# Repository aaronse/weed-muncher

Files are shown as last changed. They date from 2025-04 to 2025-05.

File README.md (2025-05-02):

# Project: Pet Sapling Savior, or, Pet Weed Euthanizer?

## Description
An Arduino or ESP32 powered, Mostly 3D‐Printed Smart Pet Weed Euthanizer/Relocator that grips unwanted plants, gently uproots them.  Use to annihilate, or deposit sapling-worthy seedlings into your chosen grow tray—combining garden cleanup, and with mini reforestation.

Inspired by conversations on V1 Engineering forum, see https://forum.v1e.com/t/how-about-a-m3dpmower/36759  topic for context/details.

Built two separate versions, a V1 Engineering Jackpot with FluidNC on ESP32, and, an Arduino Nano 33 IoT version.

.STL files available on [Printables](https://www.printables.com/model/1276001-pet-weed-euthanizer-or-pet-sapling-savior-in-progr)

This Project was inspired by conversations on V1 Engineering forum, see https://forum.v1e.com/t/how-about-a-m3dpmower/36759  topic for context/details.   

ASMR video of earlier Iteration #2 tests…



<table><tr>
<td>

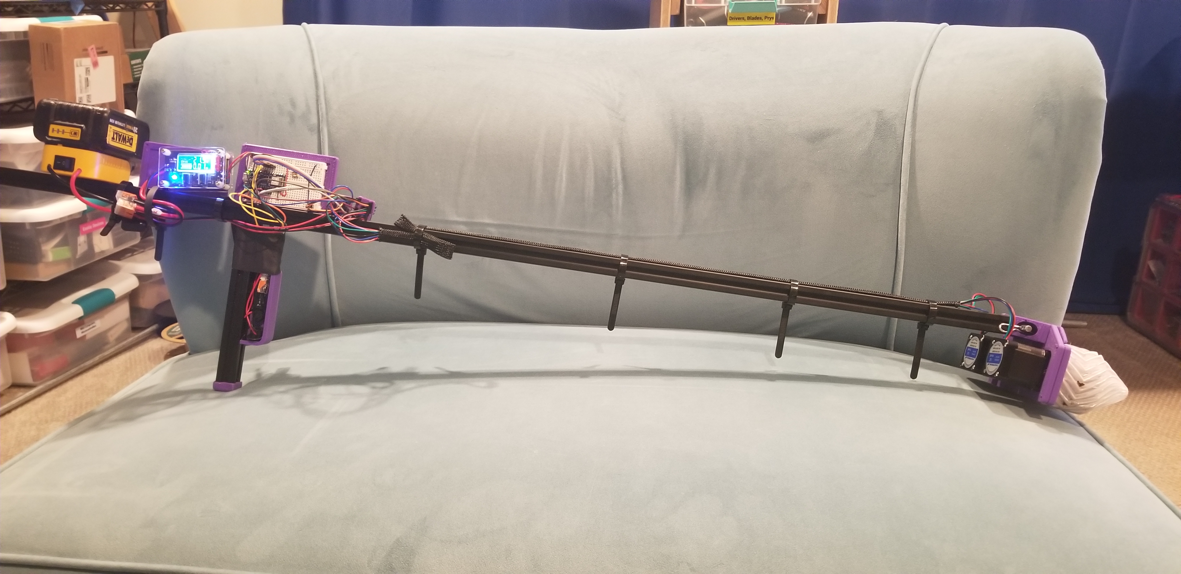
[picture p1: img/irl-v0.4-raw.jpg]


</td>
<td>

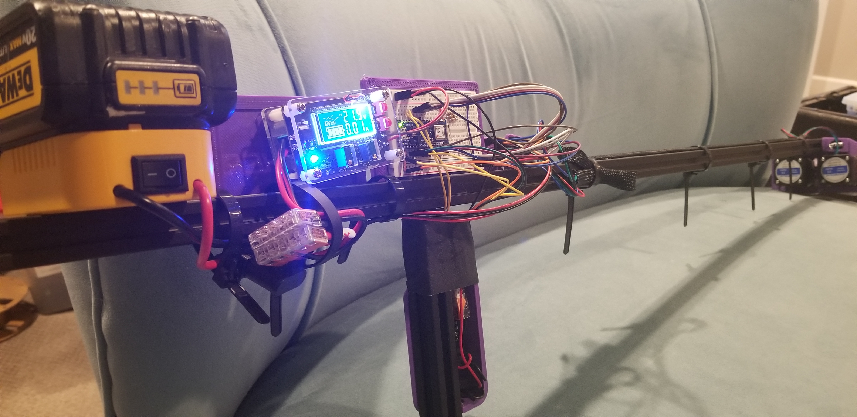
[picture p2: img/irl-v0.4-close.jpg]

</td>
<td>

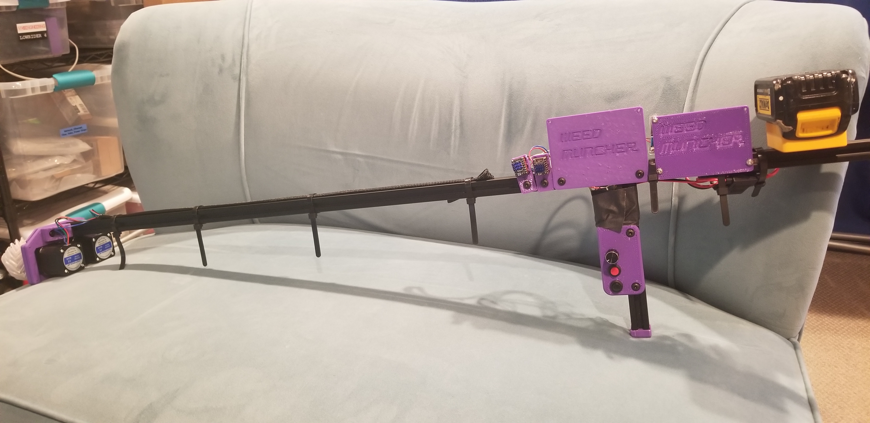
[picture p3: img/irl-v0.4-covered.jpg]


</td>
</tr></table>

### WHY?
- I hate weeding, and avoid chemicals, plus I'd like to relocate otherwise unwanted saplings to areas needing reforesting, or, yards of people that like/deserve weeds 😉.
- Best selling Weeders are unable to grip smaller weeds/saplings like the ton of Maple tree ones that drove me to this. 
- This is Phase 1 of having IOT+AI powered machines to do my bidding, before they make me do theirs.
 
### WHAT's SPECIAL?
- Fast cordless yard fun way to relocate pet saplings, or, euthanize pet weeds.  
- Design includes many components that can be repurposed for other DIY tools.
- Uses mix of TPU infill/density and [Linear Spring Compliant Mechanisms](https://forum.v1e.com/t/linear-spring-compliant-mechanisms-designing-calculating-force-and-deflection/48891) to simulate pressure exerted by human hands gripping and pulling saplings/weeds without breaking them (well tries too...). 
- Today's chemical free [Best selling Weeders](https://www.amazon.com/gp/bestsellers/lawn-garden/553934) are designed for either large deep rooted weeds, or, for people to bend and kneed down to grip and pull out small weeds by hand.  There's got to be a better way...  Maybe this DIY tool ?
- Pulling small saplings/weeds saves time compared to repeatedly cutting/trimming weeds until their root system exhausts and dies.
- **NO Coding** needed for FluidNC controller board based builds.  Just upload [config.yaml](fluidnc/config.yaml) via Web UI, restart, then go relocating/hunting...

## Functions
- Grip, pull and discard, or, collect for relocation.
- Normal grip and pull.
- Turbo grip and pull, mode for rapid munching, and suborbital sapling/weed launching. 

## 2. Software & Hardware

- [x] **Software List**: CAD/design tools and libraries...
  - [VS Code](https://code.visualstudio.com/), [Arduino IDE](https://www.arduino.cc/en/software/), [PlatformIO](https://platformio.org/), [FluidNC](http://wiki.fluidnc.com/en/home)/[ESP3D](https://github.com/luc-github/ESP3D), [Fusion 360](https://www.autodesk.com/products/fusion-360), [OpenSCAD](https://openscad.org/), [Fritzing](https://fritzing.org/).

- [x] **Hardware List**: 
    - BOM contains latest set of parts that are working for me.  I tried many more components than what are listed here.  Let me know if you want to see the full list, only shared subset here to keep instructions straight forward.   
      - Recommend 2x Nema 17 84oz with 2x TMC2209 for max pulling fun :-)
      - **Power**:
        - [AI chat about Buck convertor options](https://chatgpt.com/share/680bc146-582c-800b-8d66-930ea82643ff)
  - [X] Provided info to build either (A) Arduino, or (B) V1 Engineering Fluid NC ESP32 based build :
    - [X] Option (A), Arduino Controller:
      - https://store.arduino.cc/products/arduino-nano-33-iot-with-headers
    - [X] Option (B), V1 Engineering JackPot Controller (ESP32, FluidNC): 
      - https://www.v1e.com/products/jackpot-cnc-controller
    
## BOM

| Total Price | Description | Link / Comments |
|---:|:---|:---|
| 27 | Arduino Nano 33 IoT with Headers [ABX00032] | "https://www.amazon.com/dp/B07WPFQZQ1<br/>- https://store.arduino.cc/products/arduino-nano-33-iot-with-headers<br/>- https://mm.digikey.com/Volume0/opasdata/d220001/medias/docus/697/ABX00032_Web.pdf<br/>- https://docs.arduino.cc/hardware/nano-33-iot/#tech-specs<br/>- https://mm.digikey.com/Volume0/opasdata/d220001/medias/docus/697/ABX00032_Web.pdf<br/>- https://docs.arduino.cc/hardware/nano-33-iot/#tech-specs" |
| 28 | STEPPERONLINE 2A 59Ncm 84oz Nema 17 Stepper Motor Bipolar 48mm | https://www.amazon.com/dp/B00PNEQKC0 |
| 10 | 12pcs 12mm Mini Latching Push Button Switch ON-Off AC 250V/1.5A 125V/3A | https://www.amazon.com/dp/B0CGTXMLKL |
| 6 | 15pcs 220uF 35V 8x12mm Electrolytic Capacitor 220 UF MFD 35 Volt 0.32x0.47in Aluminum Capacitors | https://www.amazon.com/dp/B0CMQCG3M8 |
| 11 | 2pcs 12V-36V DC Voltage Protection Module Digital Low Voltage Protector Disconnect Switch Over Discharge Protection Module | https://www.amazon.com/dp/B07QNXM4LS |
| 16 | 2pcs Switched, Fused Power Adapter for Dewalt 20V Battery | https://www.amazon.com/dp/B0CRK9CN4D |
| 21 | 28pcs WAGO 221 Lever Nuts, Assortment with Case, Includes 221-2401, 221-412, 221-413, 221-415 | https://www.amazon.com/dp/B0CJ5QF3VX |
| 9 | 6pcs ELEGOO Half Breadboard Kit (400 Points, 2 pairs of power rails) | https://www.amazon.com/dp/B0CYPVMK9J |
| 10 | 630pcs BOJACK 0-to-1M Ohm 1% 1/4W (17 diff values) Metal Film Resistor Kit | https://www.amazon.com/dp/B07QXP4KVZ |
| 15 | DROK LCD Screen DC Buck Converter Adjustable Voltage Regulator 12V 6V-32V to 1.5-32V 5A, LCD Screen Step Down Converter with USB Port and Protective Case | https://www.amazon.com/dp/B07JZ2GQJF |

### 3. Wiring Diagram
- [X] Draw clear schematic (PNG/PDF).
- [X] Annotate each connection with a brief caption.

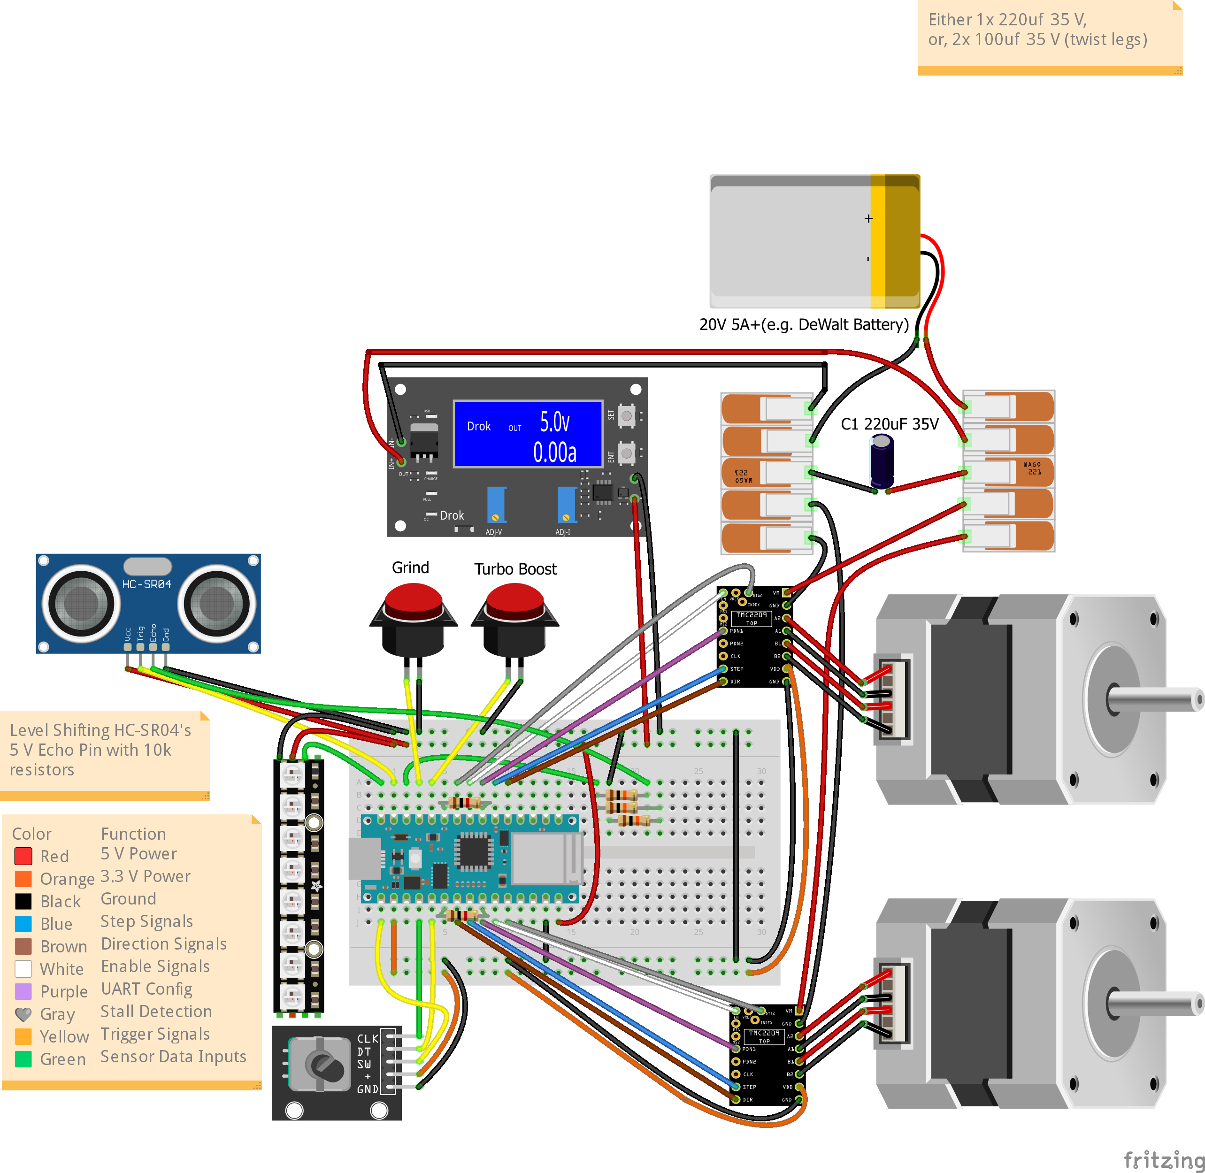
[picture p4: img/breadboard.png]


### Arduino Nano 33 IoT (3.3 V logic)

| Function | Board Pin | Device Pin | Wire Color |
|---|---|---|---|
| STEP1 | D3 | STEP | 🟦 Blue |
| DIR1 | D2 | DIR | 🟫 Brown |
| EN1 | D5 | EN | ⬜ White |
| TX1 (to PDN_UART1) | D7 | TX (with 1kΩ) | 🟪 Purple  |
| RX1 (from PDN_UART1) | D4 | RX | 🟪 Purple  |
| StallGuard1 (DIAG1) | D6 | DIAG | 🩶 Gray |
| STEP2 | D18 | STEP | 🟦 Blue |
| DIR2 | D17 | DIR | 🟫 Brown |
| EN2 | D20 | EN | ⬜ White |
| TX2 (to PDN_UART2) | D16 | TX (with 1kΩ) | 🟪 Purple  |
| RX2 (from PDN_UART2) | D19 | RX | 🟪 Purple  |
| StallGuard2 (DIAG2) | D21 | DIAG | 🩶 Gray |
| Rotary Encoder CLK | D14 | CLK | 🟩 Green |
| Rotary Encoder DT | D15 | DT | 🟨 Yellow  |
| Rotary Encoder SW | D13 | SW | 🟨 Yellow  |
| Turbo Button | D8 | Button | 🟨 Yellow  |
| Grind Button | D9 | Button | 🟨 Yellow  |
| US Trigger (TRIG) | D11 | Trigger | 🟨 Yellow  |
| US Echo (ECHO) | D10 | Echo | 🟩 Green |
| NeoPixel Data | D12 | NeoPixel | ⬜ White |

### 4. Code
- [x] Fully commented Arduino sketch.
- [x] Summary of code behavior.
  - The Weed Puller wakes up by setting up its buttons, rotary encoder, and motor drivers for smooth control and stall detection. It reads the Grind and Turbo buttons, the rotary encoder for speed adjustment, and the encoder switch to set the pulling direction.

  - Pressing Grind lets you pull weeds at a custom speed; Turbo gives you max power instantly. If the motors detect a stall, the system shuts them down and flashes a red warning until you're ready to go again. It also keeps an eye on weed distance with an ultrasonic sensor and shows real-time status over USB for easy debugging.

- [x] Full code repository at [https://github.com/aaronse/weed-muncher](https://github.com/aaronse/weed-muncher)

### 5. 3D Printing Instructions

| Qty | File Name | Material | Layer Height | Infill | Support | Print Settings | Purpose/Comment |
|:---|:---|:---|:---|:---|:---|:---|:---|
| 1 | chasis.stl | PETG | 0.32mm | 40% | No | 0.6mm noz, 3 walls, 3 top/bot layers | Mount grinder assembly to pole mounts |
| 1 | grinder-tire-tapered.stl | HS TPU | 0.32mm | 0% | No | 0.6mm noz, 1 wall, 1 top/bot layer | Tapered double helical grip 'n pull |
| 1 | grinder-tire-tapered-mir.stl | HS TPU | 0.32mm | 0% | No | 0.6mm noz, 1 wall, 1 top/bot layer | Mirrored evil twin for meshing. |
| 2 | grinder-core.stl | PETG | 0.32mm | 40% | No | 0.6mm noz, 3 walls, 3 top/bot layers | Based on metal 2020 right angle brackets, but customized for this build |
| 1 | grinder-flex-mount.stl | PETG | 0.32mm | 40% | No | 0.6mm noz, 3 walls, 3 top/bot layers | Plate to mount Steppers motors with integrated Linear spring compliant mechanism. |
| 1 | guard-grip-gt2.stl | PETG | 0.32mm | 40% | No | 0.6mm noz, 3 walls, 3 top/bot layers | Holds brackets, and grips dust/debris guard to protect steppers. |
| 2 | 2020-bracket-right-angle.stl | | 0.32mm | 40% | No | 0.6mm noz, 3 walls, 3 top/bot layers | Mount pole to grinder assembly. |
| 2 | 2020-cap.stl | HS TPU | 0.32mm | 20% | No | 0.6mm noz, 3 walls, 3 top/bot layers | End CAPs to make 2020 less stabby. |
| 0 or 1 | 2020-mount-breadboard-half.stl | PETG | 0.32mm | 20% | No | 0.6mm noz, 3 walls, 3 top/bot layers | ONLY Arduino build.  Mount for half breadboards, includes logo upside down, trick print.  Consider the separate _base_ and _frame_ versions if your printer bed isn't sticky. |
| 0 or 1 | 2020-mount-breadboard-half-base.stl  | PETG | 0.32mm | 20% | No | 0.6mm noz, 3 walls, 3 top/bot layers | ONLY Arduino build, maybe…  This "base" and "frame" are for the meek not comfortable printing engraved logo upside down. |
| 0 or 1 | 2020-mount-breadboard-half-frame.stl | PETG | 0.32mm | 20% | No | 0.6mm noz, 3 walls, 3 top/bot layers | ONLY Arduino build, maybe…  See above |
| 0 or 2 | 2020-mount-tmc2209.stl | TPU | 0.32mm | 20% | No | 0.6mm noz, 3 walls, 3 top/bot layers | ONLY Arduino build.  Temporary mounts for TMC2209 until I figure out better solution.  They don't fit in breadboards. |
| 0 or 1 | 2020-mount-jackpot.stl | PETG | 0.32mm | 20% | No | 0.6mm noz, 3 walls, 3 top/bot layers | ONLY for V1 Engineering Jackpot build |
| 0 or 1 | trigger-lefty.stl | PETG | 0.32mm | 40% | No | 0.6mm noz, 3 walls, 3 top/bot layers | ONLY if User is Left handed |
| 0 or 1 | trigger-righty.stl | PETG | 0.32mm | 40% | No | 0.6mm noz, 3 walls, 3 top/bot layers | ONLY if User is Right handed |

### 6. Assembly Instructions
- [ ] Step-by-step bullets (e.g. “1. Insert stepper into jaw housing; 2. Route wires through handle; …”).
- [ ] Alignment or torque tips (e.g. jaw mesh clearance).

### 7. Demo & Usage Instructions
- [ ] Power-on and mode selection (Pull vs. Release).
- [ ] Operating tips (e.g. hold at 30° angle, watch for stall-flash).
- [ ] Safety note (keep fingers clear of gears).

### 8. Additional Notes & Tips
- [ ] Troubleshooting pointers (e.g. check wiring if it stalls).
- [ ] Optional enhancements (e.g. add LCD status display).

### 9. Photos & Videos
- [ ] Finished product: multiple angles.
- [ ] Wiring close-ups.
- [ ] In-action demo GIF or short video (pull + relocate cycle).

- Trigger Design
  - https://www.youtube.com/watch?v=H3J8FiLNEtc
  1:07
  - Airwolf trigger, turbo, rockets...
    - 0.35 https://www.youtube.com/watch?v=PigDNRQyNwE
https://installer.fluidnc.com/

## Firmware
- FluidNC
  - http://wiki.fluidnc.com/en/config/control
  - Macros http://wiki.fluidnc.com/en/config/macros
  - Configuring Pins http://wiki.fluidnc.com/en/config/config_IO
  - ESP32 Dev Kit Pins http://wiki.fluidnc.com/en/hardware/esp32_pin_reference
  - IPC via WebSockets/TCP http://wiki.fluidnc.com/en/support/interface/websockets
  - 

## TODO/TASKS
- CAD Design edits
  - Prevent weeds sneaking behind, add funnel/guide?

  - Grinder Assembly
    - Grinder Core
      - Add lip to stop tire pulling towards Flex Mount plate
    - Grinder Tire
      - Reduce rotation angle so 0.4mm layer height slicer doesn't add "top" line segments. 
      - Prevent slip off: More bumps/recesses, or make existing bigger?
      - Modify design so Slicer 0.72mm wall width results in _inner hub wall_ and _tooth wall_ touching/bonding.

## HISTORY
- 1st Tire Print 
  - (3hr 12mins, 15% retractions) Slicer config: 2 walls, alternative wall, infill 20%, 0.32mm layer height
  - Stiffer than expected
- 2nd Grinder Tire print ()
  - (1hr 51mins, 11%) Slice config: 2 walls, 0.66mm, line width, NO alternative wall, 0% infill, 0.36mm layer height
    - ⚠️🤷‍♂️ Counter intuitively, SAVED print time using 0.32mm layer height instead of 0.4mm.  Reason is steep overhang angle of the gear teeth results in more wall material being added, when laying thick layers like 0.4mm.  Added task to reduce rotation angle of sweep, so thicker faster single walls are possible, 
  - Goals flexible print that still grips Grinder Core

## DESIGN
- Grinder Flex Mount
  - Design uses _stepped recess bore holes_, looked at [various bottom recess options](./docs/cads-flat-bottom-recess.htm)
   - To support grabbing weeds of varying thickness, the design uses linear spring compliant mechanism for resistive flex.  Goal is 30N or more resistive force, 3.5mm limited range of motion.
     - Considered [pros/cons of various materials for compliant mechanisms](./docs/compliant-mechanism-materials.htm)
     - Considered [various Open Source FEM software](./docs/fem-software-options.htm)
  - Intentionally spaced mount holes 1" OC for optional pegboard mounting.

- Grinder Wheel Treads
  - Design has conical features with tiller
    - Fusion 360 Coils swept along spiral tapered path 
    - https://www.youtube.com/watch?v=8WW2_HtuV9A
  - Morley Kert, Fusion 360 "Create Form" to make twisted scaled structures Twist
    - https://www.youtube.com/watch?v=FTLb_tus4F4

- Pole to Grinder mounts
  - History/context:
    - Was concerned about 3D print being strong enough.  Designing and printing anyway to confirm/correct my understanding/theory with data...
    - Considered 3D printed like... 
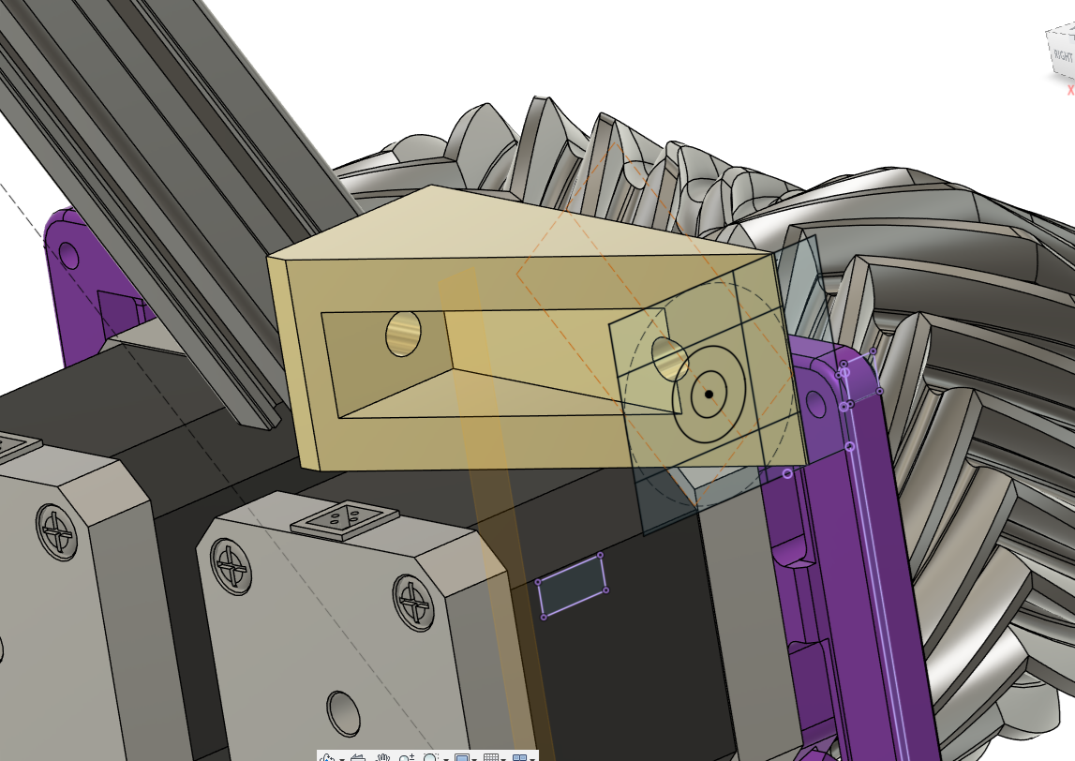
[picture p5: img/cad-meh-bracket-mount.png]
      
    - Considered common easy to source brackets.  Ideally 1" wide with centered holes.
      - Best Selling Corner Braces https://www.homedepot.com/b/Building-Materials-Building-Hardware-Corner-Braces/N-5yc1vZc8hr 
      - https://www.homedepot.com/p/Everbilt-1-in-Steel-Zinc-Plated-Corner-Brace-4-Pack-24590/327599496

## ALTERNATIVE HARDWARE CONSIDERED

- PegBoard (alternative to CNC/Printed plates).
  - Popular 1" OC, 1/4" holes, Pegboard at HomeDepot:
    - Best Seller... Hardboard, painted White Acrylic  [48 in. H x 24 in. W White Pegboard](https://www.homedepot.com/p/Handprint-48-in-H-x-24-in-W-White-Pegboard-109099/202093803)
    - [16 in. H x 16 in. W Plastic Pegboard in Black (50 lbs.)](https://www.homedepot.com/p/Everbilt-16-in-H-x-16-in-W-Plastic-Pegboard-in-Black-50-lbs-814450/317815422)
    - Some popular/accessible options...
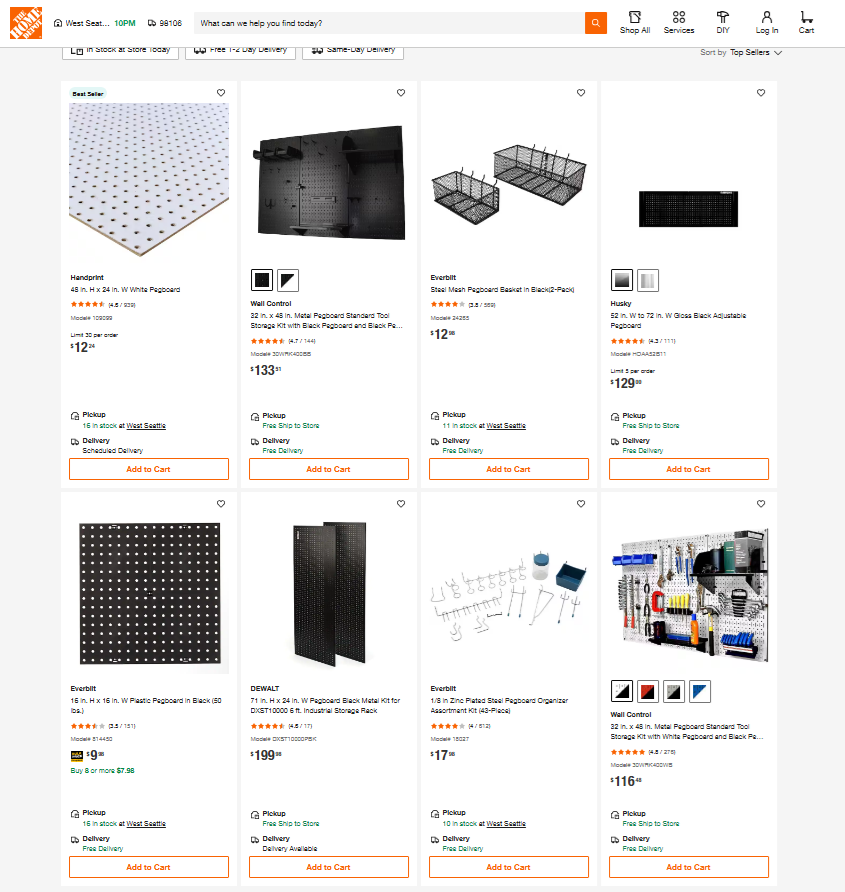
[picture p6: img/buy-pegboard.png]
image|845x892,50%
      

## 📄 License

⚠️ This project is for **personal, non-commercial use only**, and is licensed under the [Creative Commons BY-NC-SA 4.0](https://creativecommons.org/licenses/by-nc-sa/4.0/) license.

You are free to:
- ✅ Use it
- ✅ Remix it
- ✅ Build your own version at home

As long as you:
- ❌ Don't sell it or make money from it
- ✅ Give credit
- ✅ Share under the same license

😏 *Interested in selling parts or kits?*  
Am open to commercial licensing.  Any help paying for my kids' college fees is appreciated, cheers!  Contact via https://github.com/aaronse/weed-muncher/issues

**Commercial use or resale of any parts, models, or derivatives is strictly prohibited.**

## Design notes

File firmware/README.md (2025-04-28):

# Firmware code for Arduino

Built within VS Code using [PlatformIO](https://platformio.org/) extension.

## Target Devices

### Arduino Nano 33 IOT with Headers
- Buy/Info/Specs
  - https://store.arduino.cc/products/arduino-nano-33-iot-with-headers
  - https://mm.digikey.com/Volume0/opasdata/d220001/medias/docus/697/ABX00032_Web.pdf
  - https://docs.arduino.cc/hardware/nano-33-iot/#tech-specs"
- Features
  - IMU LSM6DS3, 6DOF, 3-axis acceleraometer, 3-axis gyroscope
    - Specs and example code https://chatgpt.com/share/680c0183-c3ec-800b-9c23-7b8a9bf442b4
  - BT/Wifi Nina W102 uBlox module 
    - https://chatgpt.com/share/680c0204-ad44-800b-958a-99003f26550e

### FUTURES: ESP32 + Cam
- Example code https://chatgpt.com/share/680c02d7-a82c-800b-a7e2-b9fce2a6de79

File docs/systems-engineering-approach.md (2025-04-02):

You're thinking like a systems architect *and* a product engineer here — and that’s exactly what this kind of project needs. Designing a powerful "AI-assisted inner loop" for hardware development means balancing **creative design**, **accurate geometry**, and **reliable iteration**, and optimizing **how we collaborate** across those stages.

Let’s define a few ways we can seriously **boost our productivity**, reduce friction, and set up a **tight feedback loop**.

---

## 🧠 **1. Clarify Roles in the Inner Loop**

| Role | Human (You) | AI (Me) |
|---|---|---|
| Creative judgment, ergonomics, purpose-driven constraints | ✅ | ❌ |
| Scripting, CAD generation, geometric patterning | ⚠️ Manual / slow | ✅ |
| Iteration, simplification, trade-off suggestions | ✅ | ✅ |
| State introspection, serialization, regeneration | ⚠️ Manual | ✅ (via custom script) |

> **Takeaway:** You steer high-level design intent + edits. I automate structure, generate suggestions, and keep designs clean and repeatable.

---

## ⚙️ **2. Build Reusable Parametric Vocabulary**

Rather than one-off scripts, we define a shared, evolving **“language of components”**, like:

- `MountBracket(innerDiameter, wallThickness, holePattern)`
- `ClawArm(length, width, pivotOffset)`
- `TimingBeltPulleySet(spacing, tensionSlot, mountType)`
- `TPUFingerPad(shape, gripProfile, attachmentMethod)`

We work in **reusable function-based patterns** for mechanical parts. Then:
- I can quickly generate new variants
- You can adjust behavior by tweaking params
- You can eventually combine these into a **modular Fusion component library**

---

## 🔁 **3. Track and Reflect on Manual Changes (Model Inspection Script)**

We'll eventually build a Fusion script that:
- Walks the assembly tree
- Extracts key geometry + transforms
- Serializes into a structured JSON or human-readable format

That lets you:
- Make tweaks directly in Fusion UI
- Export the **state delta**
- Send it back here for clean regeneration or AI-assist tuning

> This closes the loop so we can go **back and forth** between your hands-on edits and my generative help.

---

## 🧩 **4. Capture "Design Context" With Lightweight Metadata**

We should annotate components in a machine-readable way so I understand more about what each piece *does*:
- `TPUFingerPad` has a `gripZone`, `mountFace`, `replaceable = true`
- `GripperArm` has `pullForceVector`, `beltTab`, `pivotAxis`

You could embed these in model naming, script comments, or exported metadata so I can reason about function, not just form.

---

## 🔧 **5. Tooling Infrastructure for Efficient Iteration**

| Tool | Purpose | Notes |
|---|---|---|
| Fusion 360 Add-In (Python) | Generate & edit assemblies | Main modeling tool |
| OpenSCAD / Preview STL | Quick sketches / testing form factor | For off-model prototyping |
| JSON Model Descriptor | Reflective state snapshot | Output from inspection script |
| VS Code + Git | Version scripts + notes | Helps track changes, see diffs |
| Screenshot or video markup | Explain tweaks visually | Feed into AI for updates or fixes |

---

## 🔊 **6. Communication Loop Optimizations**

- You can tell me: *"Rotate gripper arms 5° inward and increase finger length to 75mm, but keep belt spacing the same."*
- I’ll parse that and rewrite your Fusion script or suggest edits to apply in the UI.
- Then you run the state-export script and we compare original vs tweaked designs.

If needed, I can even auto-generate UI overlays or future in-browser design editors based on your design language.

---

## 🚀 Summary: Optimized AI-Human Design Loop

1. **Start** with parametric component scripts
2. **Edit** in Fusion UI manually when needed
3. **Reflect** changes via inspection/serialization script
4. **Iterate** with my help using context-aware reasoning
5. **Repeat**, accumulating reusable parametric functions

---

If you're ready, I can generate:
- A **scripting starter structure** for Fusion 360
- The **component vocabulary** as callable Python functions
- A draft JSON schema for later model inspection

Want to go in that direction next?

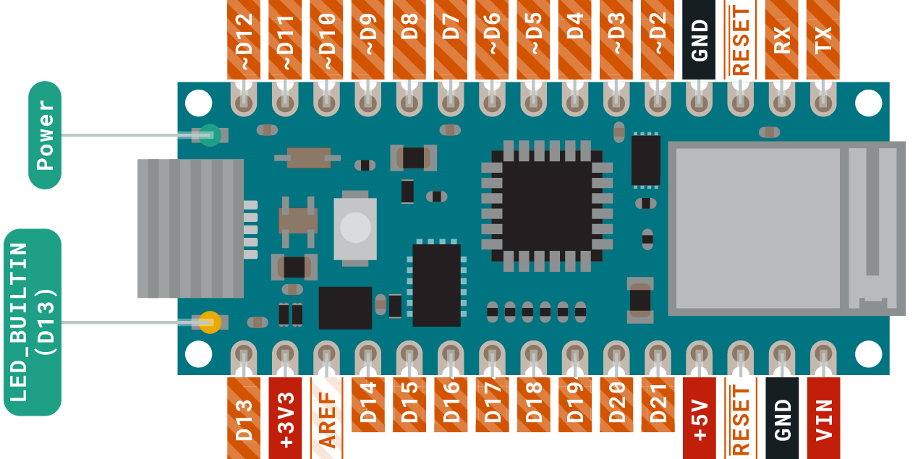
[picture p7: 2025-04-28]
img/Pinout-NANO33IoT_latest_min.png

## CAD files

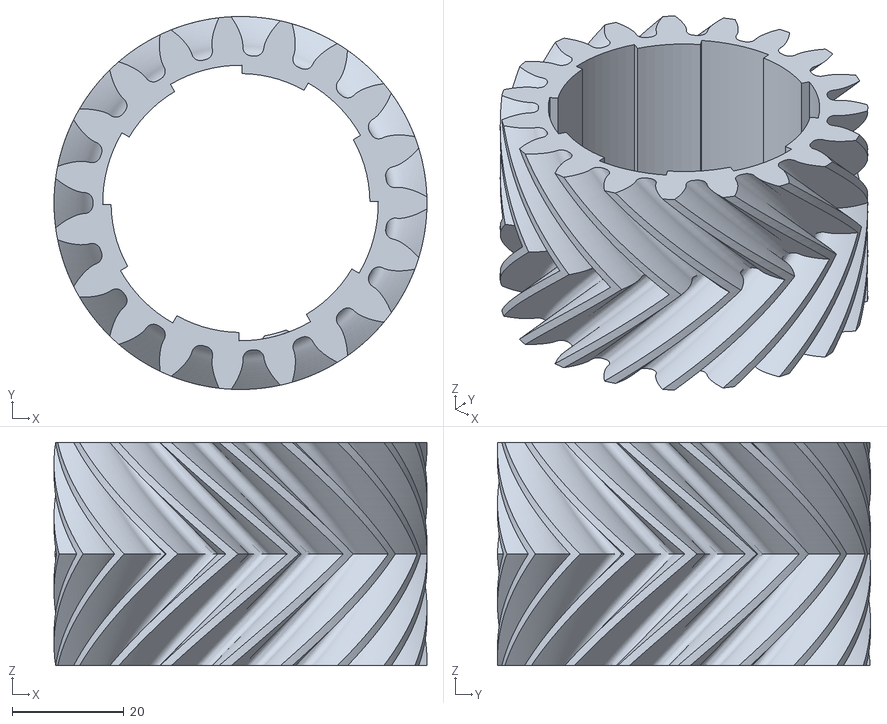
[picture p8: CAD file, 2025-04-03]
models/grinder-tire.stl
66.8 x 66.8 x 40.0

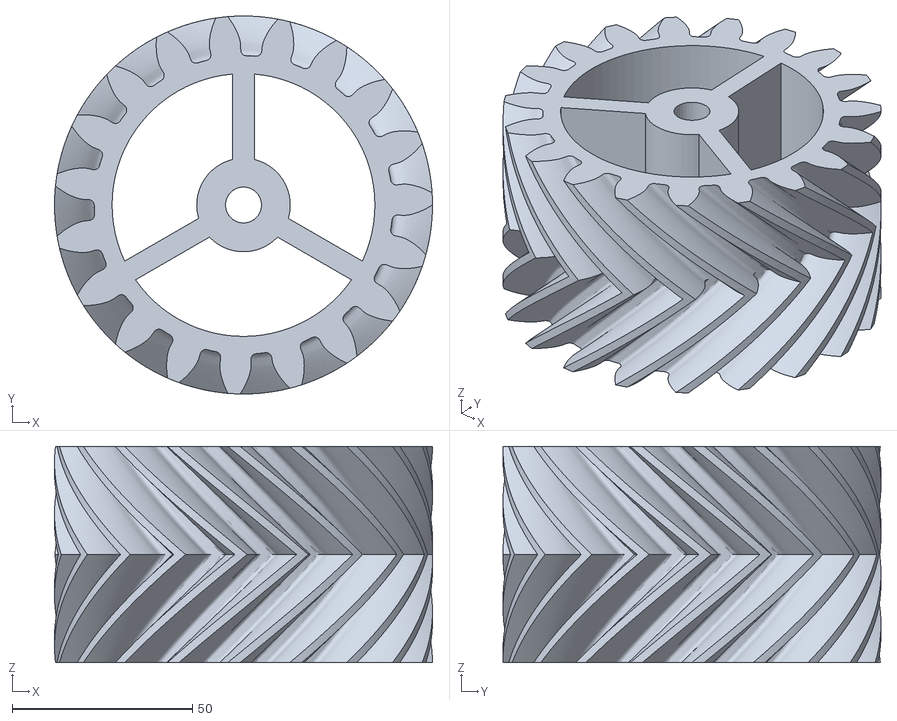
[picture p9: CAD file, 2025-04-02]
models/grinder-mir.stl
105.0 x 105.0 x 60.0

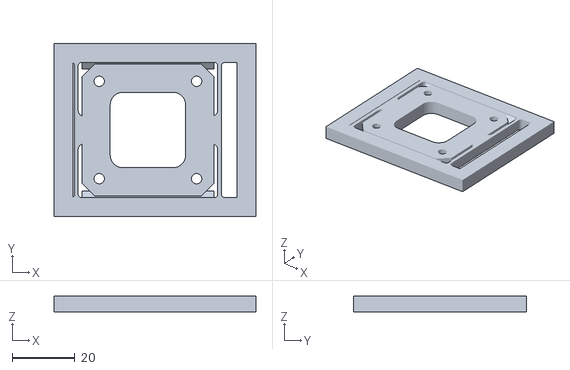
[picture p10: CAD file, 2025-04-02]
models/test-mount-spring-nema-17-1w-x-4h.stl
64.3 x 55.0 x 5.00

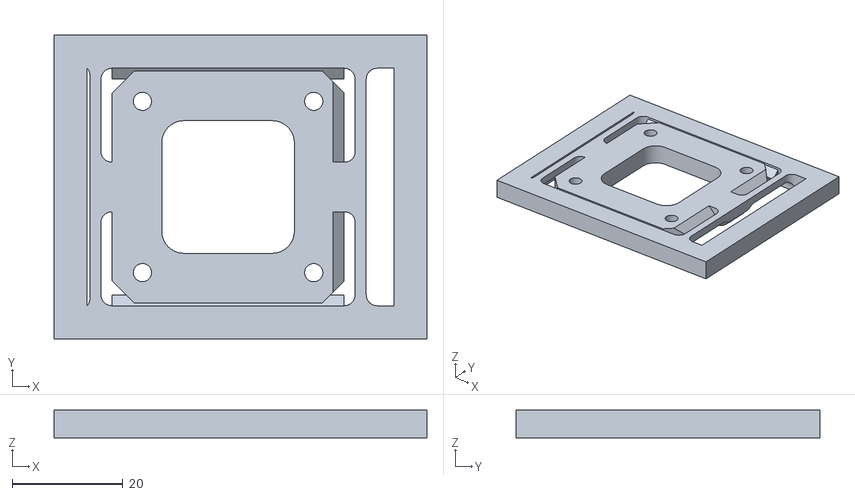
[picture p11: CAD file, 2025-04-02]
models/test-mount-spring-nema-17.stl
67.5 x 55.0 x 5.00

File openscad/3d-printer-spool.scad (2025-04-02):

// ==== PARAMETERS ====
// Filament spool
spool_outer_diameter = 200;
spool_outer_thickness = 3;
spool_hub_diameter = 80;
spool_hub_thickness = 61;
spool_core_diameter = 55;

// EMT conduit (1/2" nominal, 16.7mm OD)
emt_outer_diameter = 16.7;
emt_wall_thickness = 1.1;  // Typical EMT
emt_length = 100;          // Sample length for modeling

// ==== MODULES ====
module filament_spool() {
    difference() {
        union() {
            // Outer side disks
            translate([0, 0, 0])
                cylinder(h = spool_outer_thickness, d = spool_outer_diameter, $fn=120);
            translate([0, 0, spool_hub_thickness])
                cylinder(h = spool_outer_thickness, d = spool_outer_diameter, $fn=120);

            // Central hub
            translate([0, 0, spool_outer_thickness])
                cylinder(h = spool_hub_thickness, d = spool_hub_diameter, $fn=120);
        }
        // Hollow core (center hole)
        translate([0, 0, -1])
            cylinder(h = spool_outer_thickness * 2 + spool_hub_thickness + 2, d = spool_core_diameter, $fn=100);
    }
}

module emt_conduit() {
    difference() {
        cylinder(h = emt_length, d = emt_outer_diameter, $fn=64);
        // Hollow center
        cylinder(h = emt_length + 2, d = emt_outer_diameter - 2 * emt_wall_thickness, $fn=64);
    }
}

// ==== RENDER ====
translate([-120, 0, 0])
    filament_spool();

translate([80, 0, 0])
    rotate([90, 0, 0])
    emt_conduit();

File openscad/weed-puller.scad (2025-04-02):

//
// WeedGripperTool v0.1
// Single-file parametric OpenSCAD example for a weed-pulling tool.
// By [Your Name or Organization], [Date]
//
// NOTES:
//  - This script is a conceptual starting point with placeholder geometry.
//  - You should refine geometry for strength, print orientation, CNC details, etc.
//  - Modules are designed to be easily re-used or rearranged as you iterate.
//
// LICENSE: Whatever license you prefer (e.g., MIT, CC-BY, GPL, etc.)
//

//----------------------------------------
// Top-Level Parameters & Constants
//----------------------------------------

// Unit conversion for convenience
function inToMM(inches) = inches * 25.4; 

// 1/2" EMT approximate dimensions
emtOD = 18;          // Outer diameter in mm (nominal ~17.9mm)
emtID = 16;          // Inner diameter in mm (nominal ~15.8mm)

// Overall tool length (EMT conduit)
toolLength = inToMM(48);  // 48" ~ 1219mm

// Handle/Lever geometry
handleHeightFromBottom = inToMM(40);  // Lever/trigger ~40" from bottom
handleOffset = 30;                   // How far handle protrudes from pipe
handleThickness = 5;                 // For extrusions, placeholders

// Jaw/gripper geometry
jawMaxSpan = 50;     // ~2" in mm, max open span of jaws
jawDepth = 30;       // Some arbitrary depth for 3D printed jaws
jawThickness = 5;    // Basic thickness for each jaw half

// Wheel / pivot geometry
useWheels = true;
wheelDiameter = 90;   // e.g., a reused 3D filament spool or small wheel
wheelThickness = 25;  // approximate thickness for spool-type wheel
wheelMountThickness = 5;

// Belt/Pulley placeholders
beltWidth = 10;   // GT2 belt 10 mm wide
pulleyOD = 18;    // Example GT2 pulley OD, placeholders
idlerOD = 8;      // Example GT2 idler OD, placeholders

// Screw & hardware parameters
boltHoleDiameter = 5.5;    // For M5 bolts
nutTrapDepth = 6;          // Param for nylock or standard nut captures
plateThicknessAcrylic = 6; // e.g., 1/4" ~ 6.35mm for acrylic
plateThicknessPlywood = 12; // e.g., 1/2" ~ 12.7mm for plywood

// Pro version includes optional AI hardware mount
ProVersion = false;  // If true, adds Pi Camera, servo/stepper placeholders, etc.

// Debug / assembly
showExploded = false; 
explodeOffset = 50;  // How far to shift components for clarity

//----------------------------------------
// Modules
//----------------------------------------

//
// 1) EMT Conduit Placeholder
//
// This is just a visual placeholder for the tube you’ll supply
// Users will purchase their own 1/2" EMT conduit (48" long).
//
module showEMT() {
    color("silver") 
    cylinder(h=toolLength, r=emtOD/2, center=false, $fn=64);
}

//
// 2) EMT Mount (for wheel pivot, for handle, etc.)
// Param: height -> the position along the EMT to mount
//        thickness -> extrude thickness
//        name -> string for identification
//
module emtMount(height, thickness=5, name="emtMount") {
    // Basic ring clamp that attaches around the EMT
    translate([0,0,height])
    difference() {
        cylinder(h=thickness, r=emtOD/2+3, center=false, $fn=64); // Outer
        cylinder(h=thickness+0.1, r=emtOD/2, center=false, $fn=64); // Subtract ID
    }
}

//
// 3) Lever/Trigger Handle
// Very rough "rifle style" handle shape for demonstration
// You can refine the shape to be more comfortable and aesthetic.
//
module handle() {
    // A simplistic handle: a vertical rectangular extrusion offset from the pipe.
    translate([emtOD/2 + handleOffset,0,handleHeightFromBottom]) {
        color("red")
        cube([handleThickness, 30, 100], center=false);
    }
}

//
// 4) Gripper Jaws
// Two opposing jaws that pinch around a center axis. 
// We'll do a simplistic shape here. Each jaw is a box with a curved tip. 
// You can adapt more specialized geometry (fingerlike shape, etc.).
//
module gripperJaws() {
    // "Left" jaw
    translate([-jawMaxSpan/2,0,0]) {
        color("green")
        union() {
            // Main block
            cube([jawMaxSpan/2, jawThickness, jawDepth], center=false);
            // Curved tip for comedic "finger" shape
            translate([jawMaxSpan/2, jawThickness/2, jawDepth/2]) {
                cylinder(h=jawThickness, r=jawThickness, $fn=32, center=true);
            }
        }
    }
    // "Right" jaw
    translate([0,0,0]) {
        color("green")
        union() {
            cube([jawMaxSpan/2, jawThickness, jawDepth], center=false);
            translate([0, jawThickness/2, jawDepth/2]) {
                cylinder(h=jawThickness, r=jawThickness, $fn=32, center=true);
            }
        }
    }
}

//
// 5) TPU Finger Pads
// Example insert that fits over the jaws or has a friction fit
// In real design, you'd ensure geometry for tension, alignment, etc.
//
module tpuFingerPad() {
    color("yellow")
    // Just a small piece that can be glued or friction-fit on top of each jaw tip.
    // We'll define a single pad; you'd instance it in place for each jaw if needed.
    translate([0,0,jawDepth]) {
        cube([jawMaxSpan/2, jawThickness, 3], center=false);
    }
}

//
// 6) Pivot/Wheel Module
// This could be a 3D-printed or CNC cut bracket that mounts a wheel or spool
// near the bottom of the tool so it can roll/pivot, making it easier to lever weeds.
// 
module pivotWheelMount() {
    // We'll place the wheel near the bottom, with the bracket around the EMT
    // For demonstration, we create a ring clamp plus an axle for the wheel
    color("blue")
    union() {
        // The clamp around the EMT
        emtMount(0, wheelMountThickness, "wheelClamp");

        // Axle for wheel
        translate([emtOD/2 + wheelDiameter/2 + 2, 0, wheelMountThickness/2]) {
            cylinder(h=10, r=3, center=true, $fn=32);
        }
    }
}

//
// 7) Wheel/Omni-wheel or spool
// The actual rolling element. Could be an omni-wheel or spool from 3D filament.
//
module pivotWheel() {
    color("orange")
    translate([emtOD/2 + wheelDiameter/2 + 2, 0, wheelMountThickness/2]) {
        cylinder(h=wheelThickness, r=wheelDiameter/2, center=true, $fn=64);
    }
}

//
// 8) Belt/Pulley/Idler placeholders
// The actual path and tension mechanism is up to you—this is just a demonstration.
//
module beltSystem() {
    color("purple")
    // Show a pulley near handle
    translate([emtOD/2 + handleOffset, 0, handleHeightFromBottom + 50]) {
        cylinder(h=beltWidth, r=pulleyOD/2, center=true, $fn=32);
    }
    
    // Show an idler near jaws (you'd refine exact positioning)
    translate([-(emtOD/2 + 10), 0, 50]) {
        cylinder(h=beltWidth, r=idlerOD/2, center=true, $fn=32);
    }
    
    // Just a placeholder belt as a rectangular block
    // In real design, you'd extrude a path or show a more accurate belt shape.
    translate([-emtOD, -beltWidth/2, 50]) 
    cube([emtOD*2, beltWidth, handleHeightFromBottom], center=false);
}

//
// 9) ProVersion Electronics
// If ProVersion is true, we add mounts for a Pi Zero, camera, servo/stepper, etc.
//
module proElectronicsMount() {
    if (ProVersion) {
        color("cyan")
        translate([emtOD/2 + handleOffset + 50, 0, handleHeightFromBottom]) {
            // Pi Zero 2W placeholder: ~65mm x 30mm board
            cube([65,30,5], center=false);
        }
        // Camera mount, servo/stepper placeholders, etc. 
        translate([emtOD/2 + handleOffset + 60, 0, handleHeightFromBottom + 60]) {
            cube([30,30,30], center=false);
        }
    }
}

//
// 10) Complete Bottom Gripper Assembly
// For clarity, we combine jaws, finger pads, belt system, etc. 
// and position them at the bottom of the EMT.
//
module bottomAssembly() {
    // We'll place everything near the bottom. 
    // In reality, you'd want a pivot or scissor mechanism to open/close jaws.
    
    // Jaws
    translate([0, -jawThickness/2, 0]) rotate([0,0,0]) {
        gripperJaws();
    }
    // Finger pads on each jaw
    // Left jaw pad
    translate([-jawMaxSpan/2, -jawThickness/2, 0]) {
        tpuFingerPad();
    }
    // Right jaw pad
    translate([0, -jawThickness/2, 0]) {
        tpuFingerPad();
    }
    
    // Example belt system that might connect up the conduit
    beltSystem();
}

//
// 11) Main Assembly
//
module mainAssembly() {
    
    // Show EMT Tube
    showEMT();
    
    // Wheel pivot near bottom
    if (useWheels) {
        pivotWheelMount();
        pivotWheel();
    }
    
    // The handle/trigger near the top
    handle();
    
    // The bottom clamp/gripper system
    bottomAssembly();
    
    // Optional Pro electronics
    proElectronicsMount();
}
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

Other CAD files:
models/grinder.stl

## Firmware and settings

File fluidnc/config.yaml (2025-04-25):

board: Jackpot TMC2209
name: LowRider
meta: 10-31-2024 RyanZ
stepping: 
  engine: I2S_STATIC
  idle_ms: 255
  pulse_us: 2
  dir_delay_us: 1
  disable_delay_us: 0
  segments: 12

uart1: 
  txd_pin: gpio.0
  rxd_pin: gpio.4
  rts_pin: NO_PIN
  cts_pin: NO_PIN
  baud: 115200
  mode: 8N1

i2so: 
  bck_pin: gpio.22
  data_pin: gpio.21
  ws_pin: gpio.17

spi: 
  miso_pin: gpio.19
  mosi_pin: gpio.23
  sck_pin: gpio.18

sdcard: 
  cs_pin: gpio.5
  card_detect_pin: NO_PIN
  frequency_hz: 20000000

kinematics: 
  Cartesian: 

axes: 
  shared_stepper_disable_pin: NO_PIN
  shared_stepper_reset_pin: NO_PIN
  homing_runs: 2
  x: 
    steps_per_mm: 50.000000
    max_rate_mm_per_min: 9000.000000
    acceleration_mm_per_sec2: 200.000000
    max_travel_mm: 1260.000000
    soft_limits: false
    homing: 
      cycle: 2
      allow_single_axis: true
      positive_direction: false
      mpos_mm: 3.000000
      feed_mm_per_min: 300.000000
      seek_mm_per_min: 1500.000000
      settle_ms: 500
      seek_scaler: 1.100000
      feed_scaler: 1.100000

    motor0: 
      limit_neg_pin: NO_PIN
      limit_pos_pin: NO_PIN
      limit_all_pin: NO_PIN
      hard_limits: false
      pulloff_mm: 4.000000
      tmc_2209: 
        addr: 0
        cs_pin: NO_PIN
        uart_num: 1
        step_pin: I2SO.2
        direction_pin: I2SO.1
        disable_pin: I2SO.0
        r_sense_ohms: 0.110000
        run_amps: 0.800000
        hold_amps: 0.700000
        microsteps: 8
        toff_disable: 0
        toff_stealthchop: 5
        use_enable: false
        run_mode: StealthChop
        homing_mode: StealthChop
        homing_amps: 0.800000
        stallguard: 0
        stallguard_debug: false
        toff_coolstep: 3

  y: 
    steps_per_mm: 50.000000
    max_rate_mm_per_min: 9000.000000
    acceleration_mm_per_sec2: 200.000000
    max_travel_mm: 2480.000000
    soft_limits: false
    homing: 
      cycle: 2
      allow_single_axis: true
      positive_direction: false
      mpos_mm: 3.000000
      feed_mm_per_min: 300.000000
      seek_mm_per_min: 1500.000000
      settle_ms: 500
      seek_scaler: 1.100000
      feed_scaler: 1.100000

    motor0: 
      limit_neg_pin: NO_PIN
      limit_pos_pin: NO_PIN
      limit_all_pin: NO_PIN
      hard_limits: false
      pulloff_mm: 4.000000
      tmc_2209: 
        addr: 1
        cs_pin: NO_PIN
        uart_num: 1
        step_pin: I2SO.5
        direction_pin: I2SO.4
        disable_pin: I2SO.7
        r_sense_ohms: 0.110000
        run_amps: 1.5
        hold_amps: 0.050000
        microsteps: 8
        toff_disable: 0
        toff_stealthchop: 5
        use_enable: false
        run_mode: StealthChop
        homing_mode: StealthChop
        homing_amps: 0.800000
        stallguard: 0
        stallguard_debug: false
        toff_coolstep: 3

    motor1: 
      limit_neg_pin: NO_PIN
      limit_pos_pin: NO_PIN
      limit_all_pin: NO_PIN
      hard_limits: false
      pulloff_mm: 4.000000
      tmc_2209: 
        addr: 3
        cs_pin: I2SO.14
        uart_num: 1
        step_pin: I2SO.13
        direction_pin: I2SO.12
        disable_pin: I2SO.15
        r_sense_ohms: 0.110000
        run_amps: 1.5
        hold_amps: 0.050000
        microsteps: 8
        toff_disable: 0
        toff_stealthchop: 5
        use_enable: false
        run_mode: StealthChop
        homing_mode: StealthChop
        homing_amps: 0.800000
        stallguard: 0
        stallguard_debug: false
        toff_coolstep: 3

  z: 
    steps_per_mm: 200.000000
    max_rate_mm_per_min: 1800.000000
    acceleration_mm_per_sec2: 80.000000
    max_travel_mm: 300.000000
    soft_limits: false
    homing: 
      cycle: 1
      allow_single_axis: true
      positive_direction: true
      mpos_mm: 3.000000
      feed_mm_per_min: 200.000000
      seek_mm_per_min: 800.000000
      settle_ms: 500
      seek_scaler: 1.100000
      feed_scaler: 1.100000

    motor0: 
      limit_neg_pin: NO_PIN
      limit_pos_pin: NO_PIN
      limit_all_pin: NO_PIN
      hard_limits: false
      pulloff_mm: 4.000000
      tmc_2209: 
        addr: 2
        cs_pin: NO_PIN
        uart_num: 1
        step_pin: I2SO.10
        direction_pin: I2SO.9
        disable_pin: I2SO.8
        r_sense_ohms: 0.110000
        run_amps: 0.800000
        hold_amps: 0.700000
        microsteps: 8
        toff_disable: 0
        toff_stealthchop: 5
        use_enable: false
        run_mode: StealthChop
        homing_mode: StealthChop
        homing_amps: 0.800000
        stallguard: 0
        stallguard_debug: false
        toff_coolstep: 3

    motor1: 
      limit_neg_pin: NO_PIN
      limit_pos_pin: NO_PIN
      limit_all_pin: NO_PIN
      hard_limits: false
      pulloff_mm: 4.000000
      tmc_2209: 
        addr: 3
        cs_pin: I2SO.19
        uart_num: 1
        step_pin: I2SO.18
        direction_pin: I2SO.17
        disable_pin: I2SO.16
        r_sense_ohms: 0.110000
        run_amps: 0.800000
        hold_amps: 0.700000
        microsteps: 8
        toff_disable: 0
        toff_stealthchop: 5
        use_enable: false
        run_mode: StealthChop
        homing_mode: StealthChop
        homing_amps: 0.800000
        stallguard: 0
        stallguard_debug: false
        toff_coolstep: 3

control: 
  safety_door_pin: NO_PIN
  reset_pin: NO_PIN
  feed_hold_pin: NO_PIN
  cycle_start_pin: NO_PIN
  macro0_pin: NO_PIN
  macro1_pin: NO_PIN
  macro2_pin: gpio.14:low:pu
  macro3_pin: gpio.13:low:pu
  fault_pin: NO_PIN
  estop_pin: NO_PIN


coolant: 
  flood_pin: gpio.2
  mist_pin: gpio.16
  delay_ms: 0

probe: 
  pin: 'gpio.36:low'
  toolsetter_pin: NO_PIN
  check_mode_start: true
  hard_stop: false

macros: 
  startup_line0: 
  startup_line1: 
  Macro0: G0 Y100
  Macro1: G0 Y200 
  Macro2: G91&G1 Y100 F10000&G90&G4 P0&M2 
  Macro3: G91&G1 Y25 F2000&G90&G4 P0&M2
  after_homing: 
  after_reset: 
  after_unlock: 
#  Macro2: $LocalFS/Run=grind_normal.nc
#  Macro3: $LocalFS/Run=grind_turbo.nc

start: 
  must_home: false
  deactivate_parking: false
  check_limits: false      # disable the pre-flight limit switch check

parking: 
  enable: false
  axis: Z
  target_mpos_mm: -5.000000
  rate_mm_per_min: 800.000000
  pullout_distance_mm: 5.000000
  pullout_rate_mm_per_min: 250.000000

user_outputs: 
  analog0_pin: NO_PIN
  analog1_pin: NO_PIN
  analog2_pin: NO_PIN
  analog3_pin: NO_PIN
  analog0_hz: 5000
  analog1_hz: 5000
  analog2_hz: 5000
  analog3_hz: 5000
  digital0_pin: gpio.26
  digital1_pin: gpio.27
  digital2_pin: NO_PIN
  digital3_pin: NO_PIN
  digital4_pin: NO_PIN
  digital5_pin: NO_PIN
  digital6_pin: NO_PIN
  digital7_pin: NO_PIN

user_inputs: 
  analog0_pin: NO_PIN
  analog1_pin: NO_PIN
  analog2_pin: NO_PIN
  analog3_pin: NO_PIN
  digital0_pin: NO_PIN
  digital1_pin: NO_PIN
  digital2_pin: NO_PIN
  digital3_pin: NO_PIN
  digital4_pin: NO_PIN
  digital5_pin: NO_PIN
  digital6_pin: NO_PIN
  digital7_pin: NO_PIN

arc_tolerance_mm: 0.002000
junction_deviation_mm: 0.010000
verbose_errors: true
report_inches: false
enable_parking_override_control: false
use_line_numbers: false
planner_blocks: 32

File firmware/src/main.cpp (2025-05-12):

#define USE_TMC2209

#include <Arduino.h>
#include "MotorCommChannel.h"
#include "MotorDriver.h"
#include "DebouncedButton.h"
#include <TMCStepper.h>   // if you use USE_TMC2209
#include <NewPing.h>      // if using sonar
#include <Adafruit_NeoPixel.h>
#include "Logger.h"

// For SERCOM pin binding
#include <wiring_private.h>  

//—[ Configuration ]————————————————————————————————————
#define R_SENSE      0.11f    // Sense resistor on your TMC2209 carrier
#define DRIVER_ADDR  0        // TMC2209 UART address (usually 0 if only one)

#define STEP1_PIN    7 // Was 3 = D3
#define DIR1_PIN     2
#define EN1_PIN      5

#define STEP2_PIN    18
#define DIR2_PIN     17
#define EN2_PIN      20

#define BTN_GRIND    9
#define BTN_TURBO    8
#define ENC_SW       13
#define ENC_CLK      14
#define ENC_DT       15

#define DIAG1_PIN    6
#define DIAG2_PIN    21

#define US_TRIG_PIN  11
#define US_ECHO_PIN  10
#define NEOPIXEL_PIN 12

// 🧠 UART1: TMC Stepper 1
#define TMC1_TX_PIN 4 // WAS 7 = D7
#define TMC1_RX_PIN 3 // WAS 4 = D4

// 🧠 UART2: TMC Stepper 2
#define TMC2_TX_PIN 16  // D16
#define TMC2_RX_PIN 19  // D19

#define US_MAX_CM    200U
#define US_INTERVAL  100U   // ms between pings

#define DEBOUNCE_MS  50U    // button debounce
#define SERIAL_RATE  115200
#define REPORT_MS    1000U // status report interval

#define ENCODER_MIN   0
#define ENCODER_MAX   100
//#define ENCODER_STEP  1 // 0-100% in 720deg rotation, fine tuning - thumb/finger fatigue 
#define ENCODER_STEP  4   // 0-100% in 180deg rotation, coarse tuning - responsive 

volatile int encoderPos = 50; // Start at middle speed
int lastEncoded = 0;
bool lastEncA = HIGH;

#define NUM_PIXELS 1
Adafruit_NeoPixel statusPixel(NUM_PIXELS, NEOPIXEL_PIN, NEO_GRB + NEO_KHZ800);

// map analog→steps-per-second
static const uint32_t MAX_SPEED_SPS   = 2000;
static const uint32_t TURBO_SPEED_SPS = 4000;


//—[ Globals & Objects ]————————————————————————————
MotorCommChannel comm1(
  "Stepper1",
  &sercom2,
  TMC1_TX_PIN,
  UART_TX_PAD_0,    // TX = PAD0
  TMC1_RX_PIN,
  SERCOM_RX_PAD_1   // RX = PAD1
);

MotorCommChannel comm2(
  "Stepper2",
  &sercom3,
  TMC2_TX_PIN, 
  UART_TX_PAD_0,      // D16 (PA22) is PAD0
  TMC2_RX_PIN,
  SERCOM_RX_PAD_1     // D19 (PA23) is PAD1
);

MotorDriver motor1(STEP1_PIN, DIR1_PIN, EN1_PIN, &comm1, 0);
MotorDriver motor2(STEP2_PIN, DIR2_PIN, EN2_PIN, &comm2, 0);

DebouncedButton btnGrind(BTN_GRIND);
DebouncedButton btnTurbo(BTN_TURBO);
DebouncedButton btnEncoderSW(ENC_SW);
NewPing sonar(US_TRIG_PIN, US_ECHO_PIN, US_MAX_CM);

enum State { ST_IDLE=0, ST_GRIND, ST_REVERSE, ST_TURBO };
State   currentState = ST_IDLE;
uint32_t lastStepUs   = 0;
uint32_t lastReportMs = 0;
uint32_t lastPingMs   = 0;
uint16_t usDistCm     = 0;


//—[ Forward Declarations ]—————————————————————————————————————————
void handleEncoder();
void updateUltrasound();
void stepMotors();
const char* stateName(State s);


//—[ Setup ]—————————————————————————————————————————
void setup() {  
  initLogger(115200);  // Pass baud rate explicitly
  debugln("🛠️  Weed Muncher Starting...");
  debug("getDriverVersion: ");
  debugln(motor1.getDriverVersion());
  

  // Set up the onboard LED (Normally pin 13 on Nano 33 IoT)
  pinMode(LED_BUILTIN, OUTPUT);

  btnGrind.begin();
  btnTurbo.begin();
  btnEncoderSW.begin();
  pinMode(ENC_CLK, INPUT_PULLUP);
  pinMode(ENC_DT, INPUT_PULLUP);
  pinMode(DIAG1_PIN, INPUT);
  pinMode(DIAG2_PIN, INPUT);

  comm1.begin();
  comm2.begin();
  motor1.begin();
  motor2.begin();
  motor1.maximizeTorque();
  motor2.maximizeTorque();

  delay(100); // Wait for motors to initialize

  debug("Motor1 UART test: "); 
  debugln(motor1.driver()->test_connection());
  //debug("Motor2 UART test: "); 
  //debugln(motor2.driver()->test_connection());

  motor1.debugDriver("Startup Motor1");
  motor2.debugDriver("Startup Motor2");


  // NeoPixel init
  statusPixel.begin();
  statusPixel.setBrightness(32);
  statusPixel.show();  // turn off
}


//—[ Main Loop ]———————————————————————————————————
void loop() {
  handleEncoder();

  // 1) update inputs
  btnGrind.update();
  btnEncoderSW.update();
  btnTurbo.update();
  updateUltrasound();

  // 2) determine new state
  State newState = ST_IDLE;
  if (btnGrind.isPressed() && btnTurbo.isPressed()) newState = ST_REVERSE;
  else if (btnTurbo.isPressed())                    newState = ST_TURBO;
  else if (btnGrind.isPressed())                    newState = ST_GRIND;
  
  // 3) on state change, (re)configure motors
  if (newState != currentState) {
    currentState = newState;
    if (currentState == ST_IDLE) {
      motor1.enable(false);
      motor2.enable(false);
      statusPixel.setPixelColor(0, statusPixel.Color(0, 0, 0));  // off
    } else {
      bool forward = (currentState != ST_REVERSE);
      motor1.setDirection(forward);
      motor2.setDirection(!forward);
      motor1.enable(true);
      motor2.enable(true);

      // Wait for motors to stabilize after enabling
      delay(100); 

      // Optional: scale current from 400mA to 1200mA based on encoderPos
      // uint16_t targetCurrent = map(encoderPos, ENCODER_MIN, ENCODER_MAX, 400, 1400); // Weak current at low speed was causing stalling
      uint16_t targetCurrent = (currentState == ST_TURBO) ? 1400 : 1000;
      motor1.setCurrent(targetCurrent);
      motor2.setCurrent(targetCurrent);
      
      motor1.debugDriver("Mode Change Motor1");
      motor2.debugDriver("Mode Change Motor2");
      

      // Set color by mode
      uint32_t color = 0;
      if (currentState == ST_GRIND)   color = statusPixel.Color(0, 255, 0);  // Green
      if (currentState == ST_TURBO)   color = statusPixel.Color(255, 255, 0);  // Yellow
      if (currentState == ST_REVERSE) color = statusPixel.Color(0, 0, 255);  // Blue
    
      statusPixel.setPixelColor(0, color);
    }

    statusPixel.show();
  }

  // 4) step if needed
  stepMotors();

  // 5) periodic status report
  if (millis() - lastReportMs >= REPORT_MS) {
    lastReportMs = millis();
    debug("State="); debug(stateName(currentState));
    debug("  EncoderPos="); debug(encoderPos);
    debug("  Dist="); debug(usDistCm); debug("cm");
    debug("  Grind=");   debug(btnGrind.isPressed());
    debug("  Turbo=");   debug(btnTurbo.isPressed());
    debug("  SW=");      debugln(btnEncoderSW.isPressed());
  }
  
  // Let the MCU breathe; saves power and reduces noise
  if (currentState == ST_IDLE) {
    // TODO:P1 Power Saving, dynamically increase delay to 50ms when no recent interaction.  Goal is to sleep longer in idle to reduce power
    delay(5);  
  }
}

// TODO:P1 Optional: Dynamic Sensitivity (e.g., Fast Spin = Bigger Steps)
void handleEncoder() {
  bool encA = digitalRead(ENC_CLK);
  bool encB = digitalRead(ENC_DT);

  // Only act on changes to A (rising/falling)
  if (encA != lastEncA) {
    lastEncA = encA;
    if (encA == encB) encoderPos += ENCODER_STEP;  // Clockwise
    else              encoderPos -= ENCODER_STEP;  // Counter-clockwise
    encoderPos = constrain(encoderPos, ENCODER_MIN, ENCODER_MAX);
  }
}


//—[ State → Name ]——————————————————————————————
const char* stateName(State s) {
  switch(s) {
    case ST_GRIND:   return "GRIND";
    case ST_REVERSE: return "REVERSE";
    case ST_TURBO:   return "TURBO";
    default:         return "IDLE";
  }
}


//—[ Stepper Tick ]———————————————————————————————————
void stepMotors() {
  if (currentState == ST_IDLE) return;

  // 1) decide target speed in steps/sec
  uint32_t speedSps;
  uint32_t baseMax = (currentState == ST_TURBO) ? TURBO_SPEED_SPS : MAX_SPEED_SPS;
  speedSps = map(encoderPos, ENCODER_MIN, ENCODER_MAX, 0, baseMax);
  
  // 2) skip stepping if zero
  if (speedSps == 0) return;

  // 3) compute interval (no digit separators)
  uint32_t intervalUs = 1000000UL / speedSps;

  // 4) non-blocking timing
  static uint32_t lastStepUs = 0;
  uint32_t nowUs = micros();
  if (nowUs - lastStepUs < intervalUs) return;
  lastStepUs = nowUs;

  // 5) fire the pulses
  motor1.stepPulse();
  motor2.stepPulse();
}


//—[ HC-SR04 Ping ]———————————————————————————————————
void updateUltrasound() {
  uint32_t now = millis();
  if (now - lastPingMs >= US_INTERVAL) {
    lastPingMs   = now;
    usDistCm     = sonar.ping_cm();
  }
}

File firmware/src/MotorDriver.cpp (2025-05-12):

#include "config.h"
#include "MotorDriver.h"
#include "Logger.h"

#ifdef USE_TMC2209
  #define EN_ACTIVE    LOW
  #define EN_INACTIVE  HIGH
  //#define TMC_SERIAL   Serial1
  // Sense resistor constant must match your board
  #ifndef R_SENSE
  # define R_SENSE 0.11f
  #endif

  // TODO:P0 Should reset and/or periodically re-evaluate _isConnected

  MotorDriver::MotorDriver(uint8_t st, uint8_t di, uint8_t en, MotorCommChannel* comm, uint8_t driverAddr)
  : _stepPin(st), _dirPin(di), _enPin(en),
    _comm(comm),
    _driver(comm->getStream(), R_SENSE, driverAddr)
  {}

  void MotorDriver::begin() {
    pinMode(_stepPin, OUTPUT);
    pinMode(_dirPin,  OUTPUT);
    pinMode(_enPin,   OUTPUT);
    
    // Allow time for driver to power up
    enable(true);
    delay(100); 

    _driver.begin();
    _driver.toff(5);
    _driver.rms_current(800);
    //_driver.microsteps(16);

    // Use coarse microstepping for max torque and efficiency.
    // Finer steps (e.g. 16+) reduce torque per pulse and increase CPU load.
    // This isn't a precision CNC — it's a torque-hungry weed puller 😎
    _driver.microsteps(2);  // Options: 2 or 4 give good torque + decent smoothness

    // 🔍 UART test
    int result = _driver.test_connection();
    _isConnected = (result == 0);
    debug("["); debug(_comm->getName()); debug("] ");
    if (_isConnected) {
      debugln("✅ UART connection OK");
    } else {
      debug("❌ UART connection FAIL (code: "); debug(result); debugln(")");
    }
    
    enable(false);
  }

  void MotorDriver::setCurrent(uint16_t mA) {
    if (isConnected(true)) {
      _driver.rms_current(mA);
    }
  }

  uint16_t MotorDriver::getDriverVersion() {
    return 2209;
  }

  bool MotorDriver::isConnected(bool autoReconnect) {
    unsigned long now = millis();
  
    if (autoReconnect && (now - _lastConnectionCheck >= 500)) {
      _lastConnectionCheck = now;
  
      int result = _driver.test_connection();
      _isConnected = (result == 0);
  
      debug("["); 
      debug(_comm->getName()); 
      debug("] Re-check UART connection: ");
      if (_isConnected) {
        debugln("✅ OK");
      } else {
        debug("❌ FAIL (code: "); 
        debug(result); 
        debugln(")");
      }
    }
  
    return _isConnected;
  }
  

#else
  // A4988 version stub
  #define EN_ACTIVE    LOW
  #define EN_INACTIVE  HIGH

  MotorDriver::MotorDriver(uint8_t st, uint8_t di, uint8_t en)
    : _stepPin(st), _dirPin(di), _enPin(en)
  {}

  void MotorDriver::begin() {
    pinMode(_stepPin, OUTPUT);
    pinMode(_dirPin,  OUTPUT);
    pinMode(_enPin,   OUTPUT);
    enable(false);
  }

  void MotorDriver::setCurrent(uint16_t) {
    // no-op: fixed by resistor
  }

  uint16_t MotorDriver::getDriverVersion() {
    return 4988;
  }

#endif

void MotorDriver::enable(bool on) {
  digitalWrite(_enPin, on ? EN_ACTIVE : EN_INACTIVE);
}

void MotorDriver::setDirection(bool forward) {
  digitalWrite(_dirPin, forward ? HIGH : LOW);
}

void MotorDriver::stepPulse() {
  digitalWrite(_stepPin, HIGH);
  delayMicroseconds(2);
  digitalWrite(_stepPin, LOW);
}


// void MotorDriver::maximizeTorque() {
//   _driver.begin();
//   _driver.toff(5);
//   _driver.rms_current(1400);          // 2.0A peak ≈ 1.41A RMS
//   _driver.microsteps(2);              // Fewer microsteps = more torque
//   _driver.en_spreadCycle(true);       // Use spreadCycle instead of stealthChop
// }

void MotorDriver::maximizeTorque() {
  _driver.begin();
  _driver.toff(5);
  _driver.rms_current(1400);              // ≈ 2.0A peak
  _driver.microsteps(2);
  _driver.en_spreadCycle(true);           // Ensure spreadCycle for torque
  _driver.pwm_autoscale(false);           // Optional: disable stealthChop tuning
  _driver.pwm_autograd(false);            // Optional: disable auto PWM
  _driver.I_scale_analog(false);          // Use internal Vref instead of analog pin
}


void MotorDriver::debugDriver(const char* label) {
  if (!_isConnected) {
    debug("["); 
    debug(_comm->getName()); 
    debug(",");
    debug(label);
    debugln("] ⚠️ UART unavailable — skipping Driver debug logic.");
    return;
  }

  if (label) {
    debug("[Driver Debug] "); debug(label); debugln(":");
  }

  uint32_t ihold_irun = _driver.IHOLD_IRUN();
  uint8_t ihold = ihold_irun & 0x1F;
  uint8_t irun  = (ihold_irun >> 8) & 0x1F;
  uint8_t delay = (ihold_irun >> 16) & 0x0F;

  debug("  IHOLD: "); debug(ihold);
  debug("  IRUN: ");  debug(irun);
  debug("  IHOLDDELAY: "); debugln(delay);
  debug("  GCONF: "); debugln(_driver.GCONF(), HEX);
  debug("  IOIN:  "); debugln(_driver.IOIN(), HEX);

  float irun_ratio = irun / 31.0;
  float approx_rms = irun_ratio * 2000.0; // if using 2.0A motors
  debug("Estimated RMS: "); debugln(approx_rms);  
}

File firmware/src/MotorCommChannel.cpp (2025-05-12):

#include "MotorCommChannel.h"

MotorCommChannel::MotorCommChannel(
  const char* name,
  SERCOM* sercom,
  uint8_t txPin,
  SercomUartTXPad txPad,
  uint8_t rxPin,
  SercomRXPad rxPad
)
  : _name(name),
    _txPin(txPin),
    _rxPin(rxPin),
    _sercom(sercom),
    _rxPad(rxPad),
    _txPad(txPad),
    _uart(sercom, rxPin, txPin, rxPad, txPad)
{}


void MotorCommChannel::begin() {
  pinPeripheral(_rxPin, PIO_SERCOM);
  pinPeripheral(_txPin, PIO_SERCOM);
  _uart.begin(115200); // Try lower if suspect poor wiring e.g. 57600
}

Stream* MotorCommChannel::getStream() {
  return &_uart;
}

const char* MotorCommChannel::getName() const {
  return _name;
}

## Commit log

2025-04-02 First backup snapshot of early stage prototypes...
    [3d-printer-spool.scad, grinder-mir.stl, grinder.stl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]
2025-04-03 Start fleshing out some docs. Added 2 stepper based grinder-flex-mount.stl
    [grinder-flex-mount.stl]
2025-04-03 Grinder tire and Grinder inner Core
    [grinder-core.stl, grinder-flex-mount.stl, grinder-tire.stl]
2025-04-24 .stl models for rough prototype...
    [2020-bracket-right-angle.stl, 2020-cable-clip-6P-22awg.stl, 2020-cable-clip-6p-22awg-brim.stl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]
2025-04-24 Firmware config snapshot, including backup and jeyeager
    [macro1.g, macro2.g, macro3.g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]
2025-04-24 v0.1 Config with button triggered macros for Normal, and Turbo...
2025-04-25 Add BOM.xlsx which contains the "truth" about .STL and Hardware parts needed. Also included bom-hardware.md as a convenient snapshot created using tab-to-markdown.py helper script to convert excel/ta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
    [BOM.xlsx]
2025-04-25 Model updates
    [2020-bracket-right-angle.3mf]
2025-04-25 Rename FluidNC related config files. Making way for Arduino code...
    [config.yaml, macro1.g, macro2.g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]
2025-04-25 Arduino Nano 33 IOT Hello World...
2025-04-28 BOM and doc edits
    [BOM.xlsx]
2025-04-28 Cleanup and remove unrequired fluidnc stuff.
    [config.yaml]
2025-04-28 Latest .STL models
    [2020-mount-breadboard-half-base.stl, 2020-mount-breadboard-half-frame.stl, 2020-mount-breadboard-half-no-logo.stl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]
2025-04-28 Convert BOM to markdown, moved to README.md for easier reading. Removed components that were tried but abandoned. Intent is to have BOM just show the parts that are needed for latest build
    [BOM.xlsx]
2025-04-28 README.md, cleanup BOM
2025-04-28 Shuffling models around to make clearer which ones should be used
    [2020-cable-clip-6P-22awg.stl, 2020-cable-clip-6p-22awg-brim.stl, 2020-mount-jackpot.stl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]
2025-05-02 Various updates to make pinout same as docs published to Printables. Speed control and Turbo aren't working though as expected, looking...
2025-05-02 ⚡Added Turbo boost...
2025-05-02 Shared models on https://www.printables.com/model/1276001-pet-weed-euthanizer-or-pet-sapling-savior where they're easier to discover, preview and print.
    [2020-bracket-right-angle.3mf, 2020-bracket-right-angle.stl, 2020-cable-clip-6P-22awg.stl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]
2025-05-02 Fixing and tuning rotary encoder responsiveness
    [main.cpp]
2025-05-02 Wrap Serial.Print with debug methods that conditionally compile, and more importantly don't block execution if USB is not connected 🤦‍
2025-05-11 Start implementing serial UART control of steppers via TX/RX to PDN pins.
2025-05-11 Implementing MotorCommChannel to handle UART via SAMD21/Nano's SERCOM implementation. Feature isn't working, but non-connected state is detected to avoid sending driver commands that will eventually 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
    [Logger.cpp, MotorCommChannel.cpp, MotorDriver.cpp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]
2025-05-12 Some edits (still broken though...) to try and get Arduino Nano 33 IoT to send/recv TMC2209 commands via UART.
    [MotorCommChannel.cpp, MotorDriver.cpp, main.cpp]
